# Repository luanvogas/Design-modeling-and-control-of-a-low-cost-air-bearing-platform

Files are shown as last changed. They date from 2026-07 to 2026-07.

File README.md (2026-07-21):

# Design, modeling, and control of a low-cost air-bearing platform

<div align="center">

This repository contains files produced as part of the doctoral thesis.

**Author:** Luan Mateus Bocalan Vogás  
**Advisor:** Prof. Dr. Roberto Kawakami Harrop Galvão  
**Co-Advisor:** Profa. Dra. Gabriela Werner Gabriel  

Instituto Tecnológico de Aeronáutica (ITA)  
Electronics Engineering Division  
São José dos Campos, SP, Brazil  
2026

</div>

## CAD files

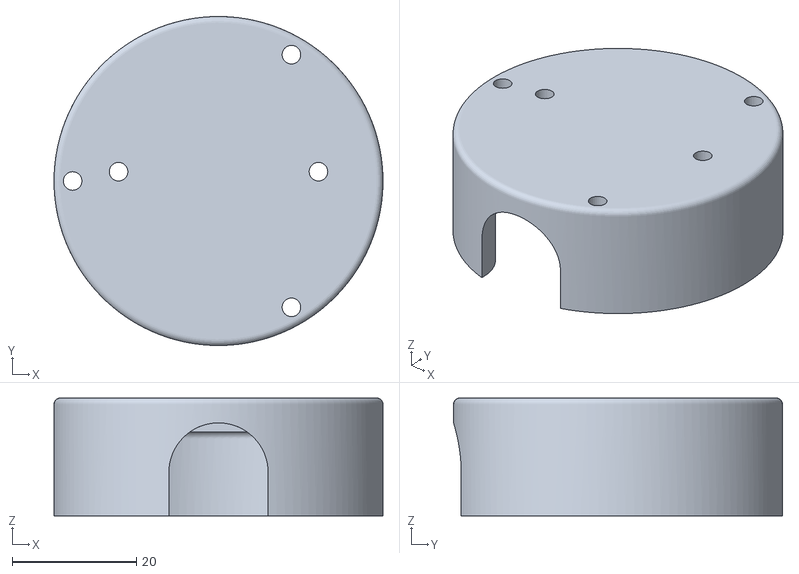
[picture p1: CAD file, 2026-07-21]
3D_models/A17_Main_part_bracket_IMU.stl
53.0 x 53.0 x 19.0

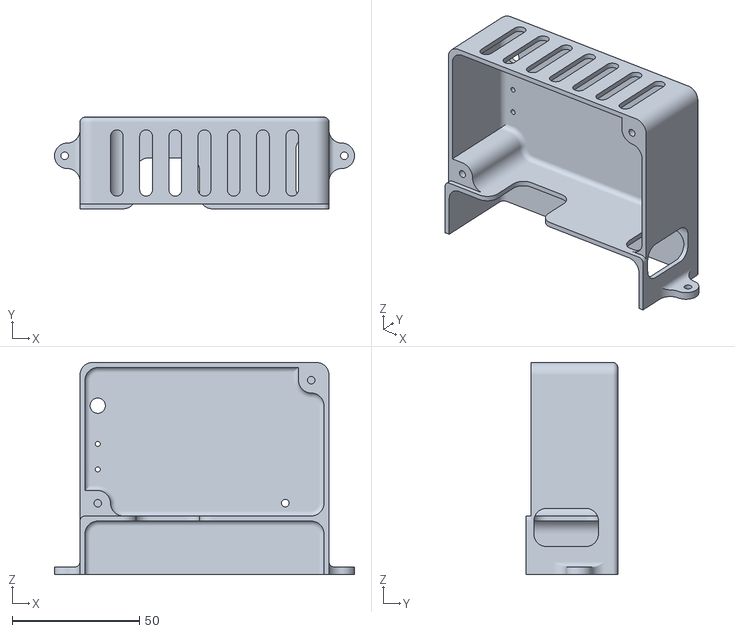
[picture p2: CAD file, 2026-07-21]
3D_models/A14_Main_part_box_electronic_boards.stl
117.8 x 36.0 x 83.3

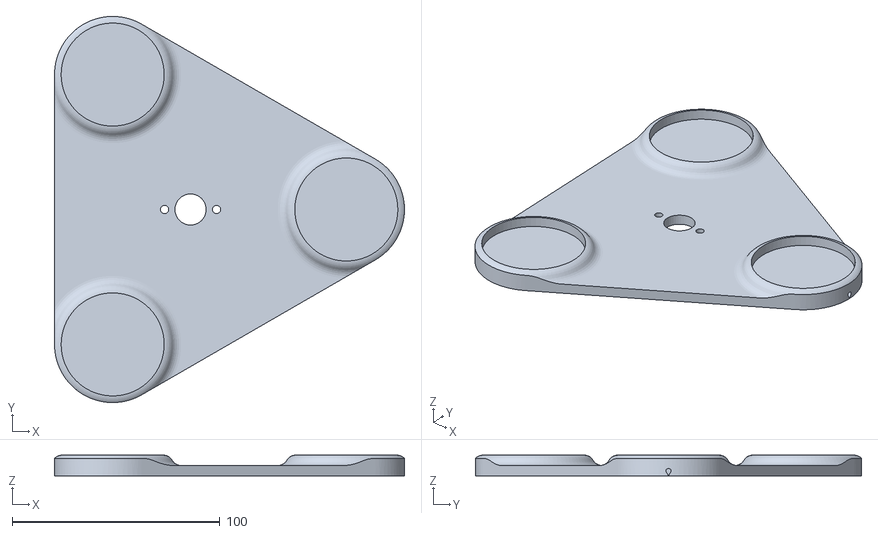
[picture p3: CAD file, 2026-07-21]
3D_models/A23_Support_servo_camera_calibration.stl
168.5 x 185.9 x 10.0

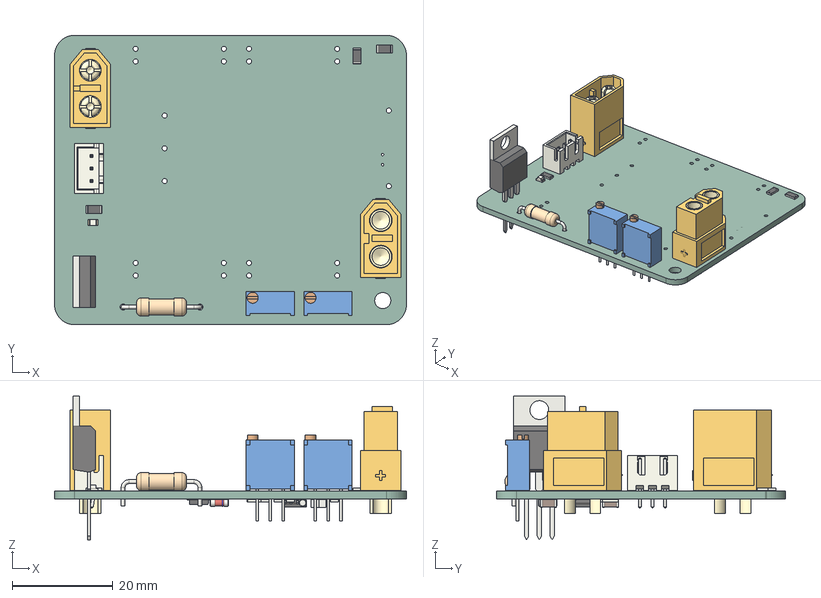
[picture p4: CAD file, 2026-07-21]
PCBs/Primary_Circuit_Board/Primary_Circuit_Board.step
69.9 x 57.4 x 28.5 mm
R_1206_3216Metric x 13
XT60 female v5
R_Axial_DIN0411_L99mm_D36mm_P1524mm_Horizontal
JST_B3B_XH_A
TO-220-3_Vertical
Potentiometer_Bourns_3296W_Vertical x 2
XT60 male v9
LED_0805_2012Metric
D_MiniMELF_Standard x 3
C_1206_3216Metric x 2
D_SOD-128
SOIC-8-1EP_3.9x4.9mm_P1.27mm_EP2.29x3mm
Power_Supply_Board_PCB

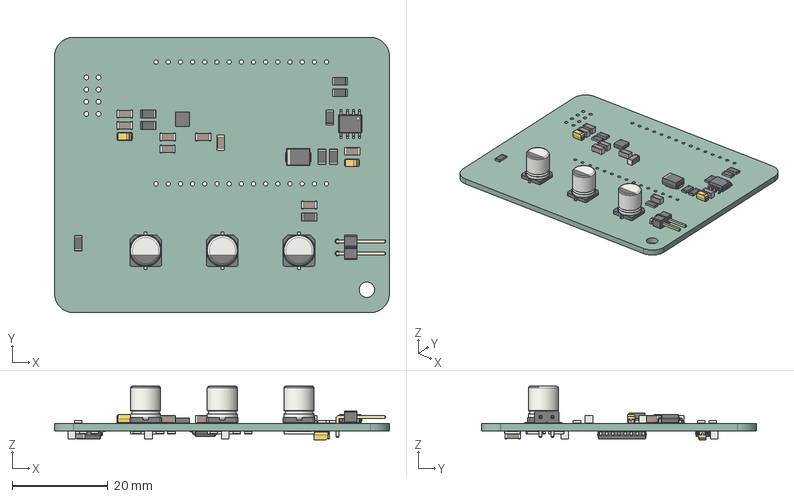
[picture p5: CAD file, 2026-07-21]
PCBs/Secondary_Circuit_Board/Secondary_Circuit_Board.step
69.9 x 57.4 x 11.2 mm
CP_Elec_63x77 x 3
R_1206_3216Metric x 20
SOIC_8_39x49mm_P127mm
C_1206_3216Metric x 13
CP_EIA_3216_18_Kemet_A x 3
D_SMB
LGA_16_3x3mm_P05mm
PinHeader_1x02_P254mm_Horizontal
SOIC_16W_75x128mm_P127mm
R_2512_6332Metric x 6
TSSOP_8_44x3mm_P065mm
Electronics_PCB

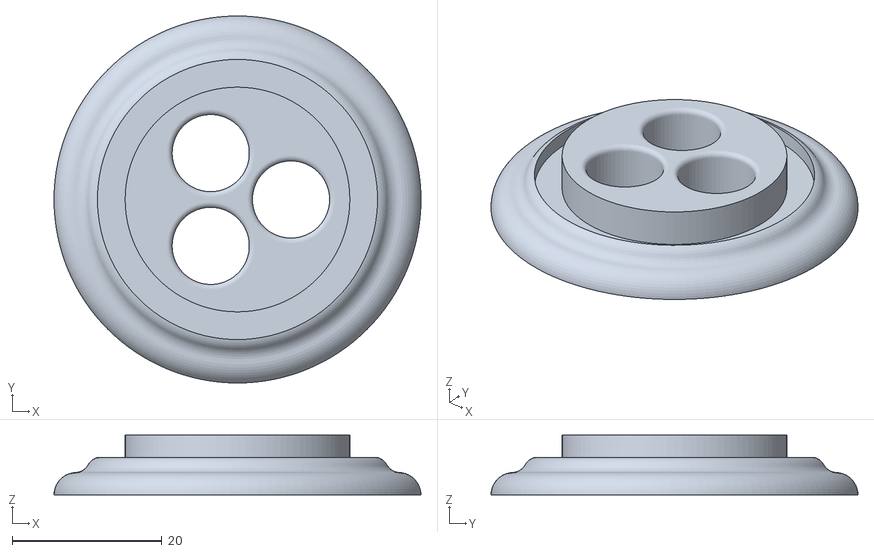
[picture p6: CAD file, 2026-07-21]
3D_models/A1_Air_bearing_base.stl
49.0 x 49.0 x 8.00

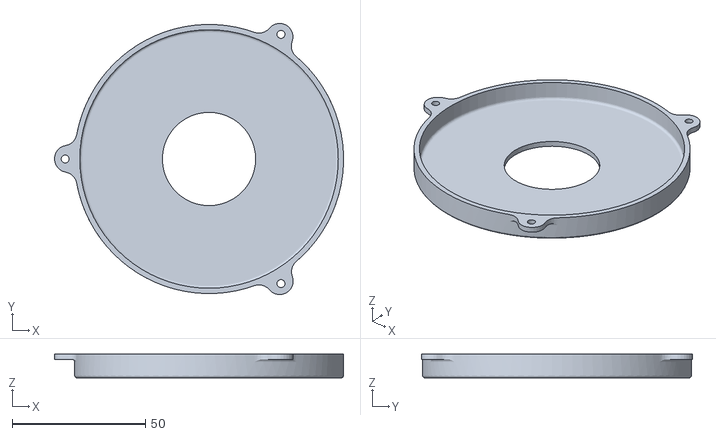
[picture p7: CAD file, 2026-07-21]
3D_models/A6_Cover_reaction_wheel.stl
108.5 x 101.8 x 9.00

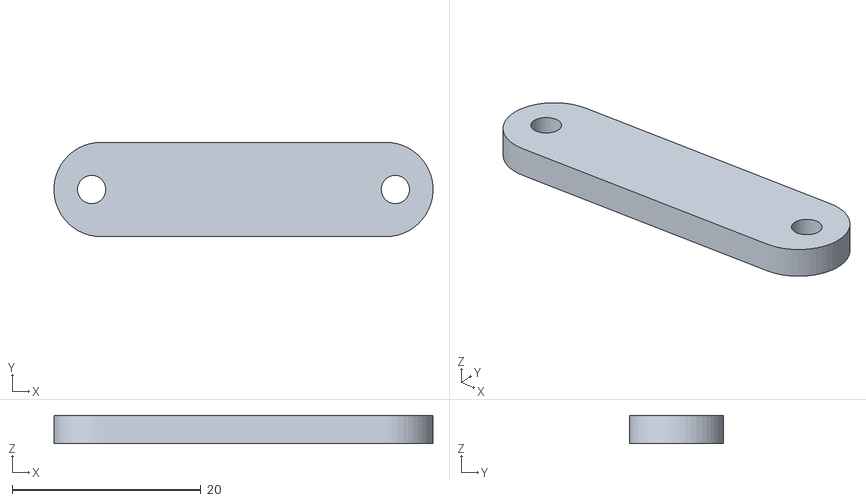
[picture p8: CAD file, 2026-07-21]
3D_models/A18_Bracket_hold_IMU_case.stl
40.2 x 10.0 x 3.00

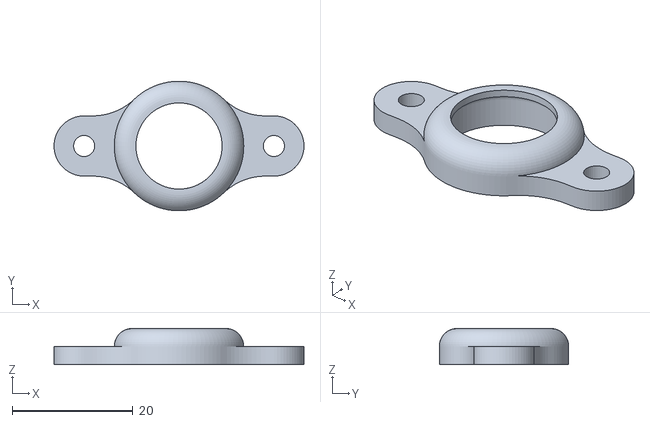
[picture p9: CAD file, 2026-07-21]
3D_models/A4_Spherical_bearing_support.stl
41.5 x 21.5 x 6.00

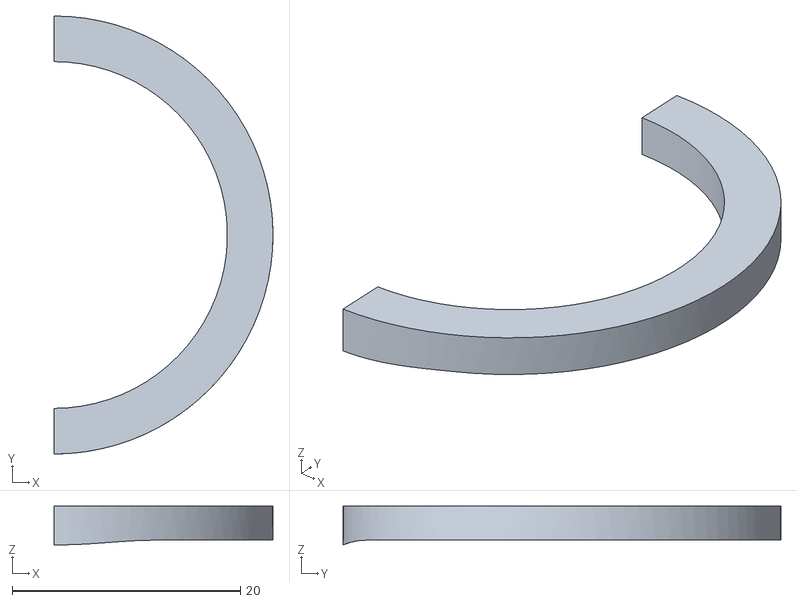
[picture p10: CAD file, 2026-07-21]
3D_models/A13_Part_2_support_pressure_regulator.stl
19.2 x 38.4 x 3.42

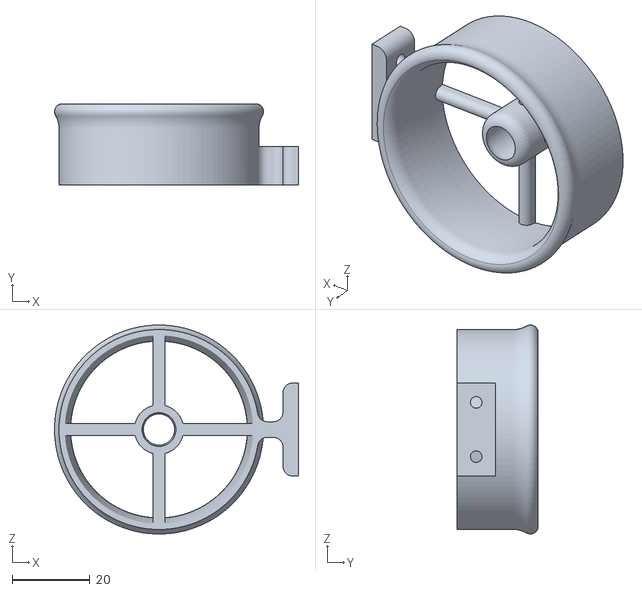
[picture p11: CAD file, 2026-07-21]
3D_models/A9_Disturbance_motor_bracket.stl
63.0 x 21.0 x 53.9

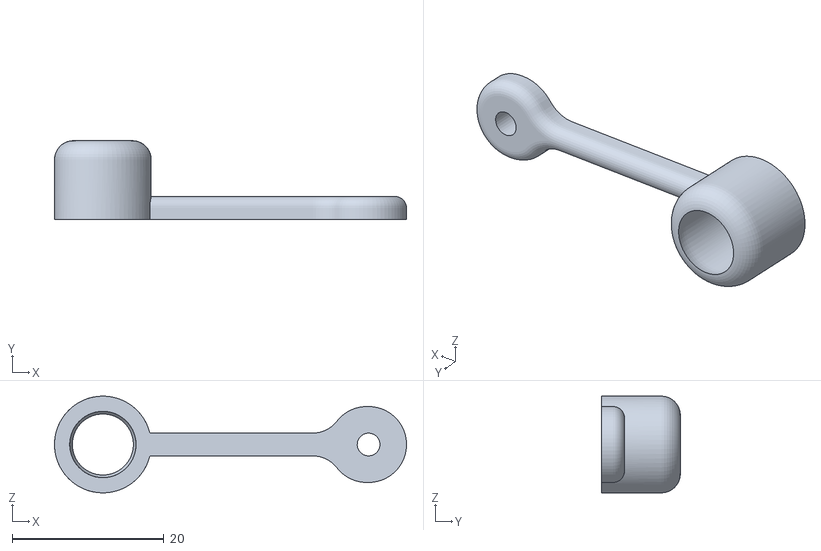
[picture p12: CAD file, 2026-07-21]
3D_models/A29_Support_motor_load_cell_without_duct.stl
46.4 x 10.4 x 12.7

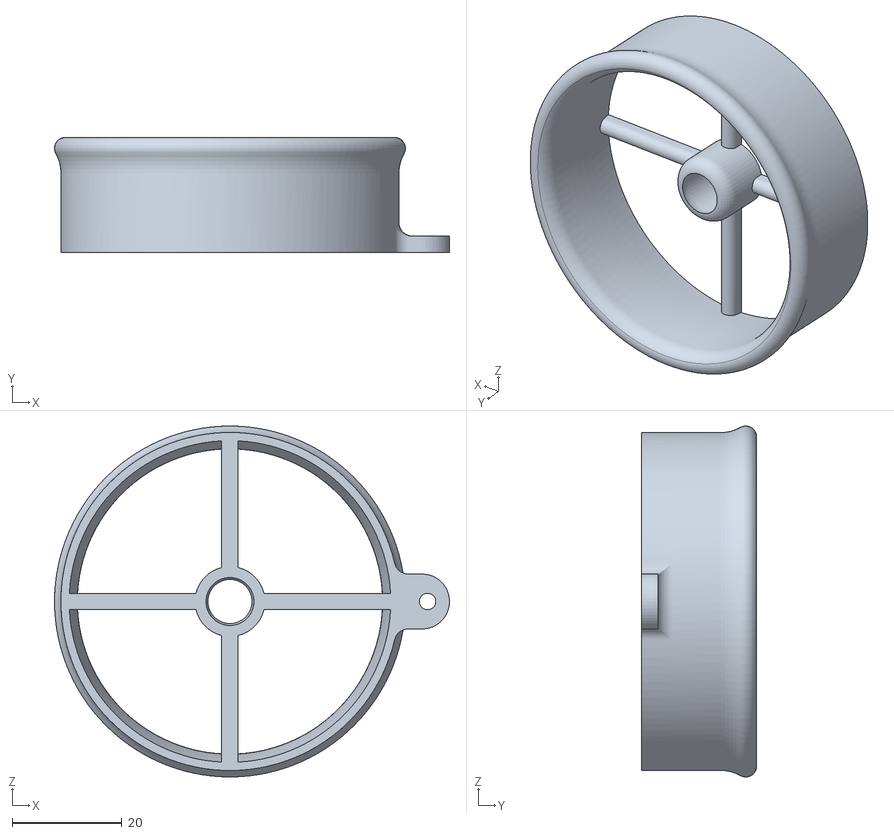
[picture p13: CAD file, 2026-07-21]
3D_models/A31_Support_motor_load_cell_55mm_duct.stl
72.0 x 21.0 x 63.9

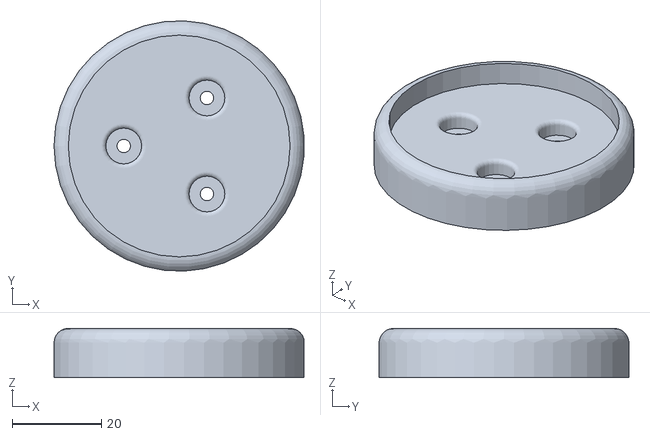
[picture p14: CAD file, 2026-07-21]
3D_models/A27_Bearing_support_RW_characterization_struture.stl
55.9 x 56.0 x 11.0

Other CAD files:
3D_models/A24_Support_table_camera_calibration.stl
3D_models/A19_Bracket_battery.stl
3D_models/A8_Top_floor_platform.stl
3D_models/A25_Lower_disc_RW_characterization_struture.stl
3D_models/A10_Part_1_support_PET_bottle.stl
3D_models/A11_Part_2_support_PET_bottle.stl
3D_models/A12_Part_1_support_pressure_regulator.stl
3D_models/A15_Bottom_part_box_electronic_boards.stl
3D_models/A16_Top_cover_box_electronic_boards.stl
3D_models/A20_Support_ArUco_marker.stl
3D_models/A21_Part_1_auxiliary_support_ArUco.stl
3D_models/A22_Part_2_auxiliary_support_ArUco.stl
3D_models/A26_Upper_disc_RW_characterization_struture.stl
3D_models/A28_Support_line_RW_characterization_struture.stl
3D_models/A2_Air_bearing_cover.stl
3D_models/A30_Support_motor_load_cell_45mm_duct.stl
3D_models/A3_Air_bearing_fixing_bracket.stl
3D_models/A5_Bottom_floor_platform.stl
3D_models/A7_Bottom_floor_motor_bracket.stl

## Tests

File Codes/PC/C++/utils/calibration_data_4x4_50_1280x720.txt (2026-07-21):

%YAML:1.0
---
calibration_time: "Mon Dec  4 14:02:41 2023"
image_width: 1280
image_height: 720
flags: 0
camera_matrix: !!opencv-matrix
   rows: 3
   cols: 3
   dt: d
   data: [ 9.6003079017747950e+02, 0., 6.4759114083780116e+02, 0.,
       9.6057532993660845e+02, 3.5647079880607180e+02, 0., 0., 1. ]
distortion_coefficients: !!opencv-matrix
   rows: 1
   cols: 5
   dt: d
   data: [ 8.0410259950618707e-02, -3.2936306621087619e-01,
       2.5844360184622602e-03, 1.5253495226606067e-05,
       3.5463308602818394e-01 ]
avg_reprojection_error: 9.7660139921601419e-01

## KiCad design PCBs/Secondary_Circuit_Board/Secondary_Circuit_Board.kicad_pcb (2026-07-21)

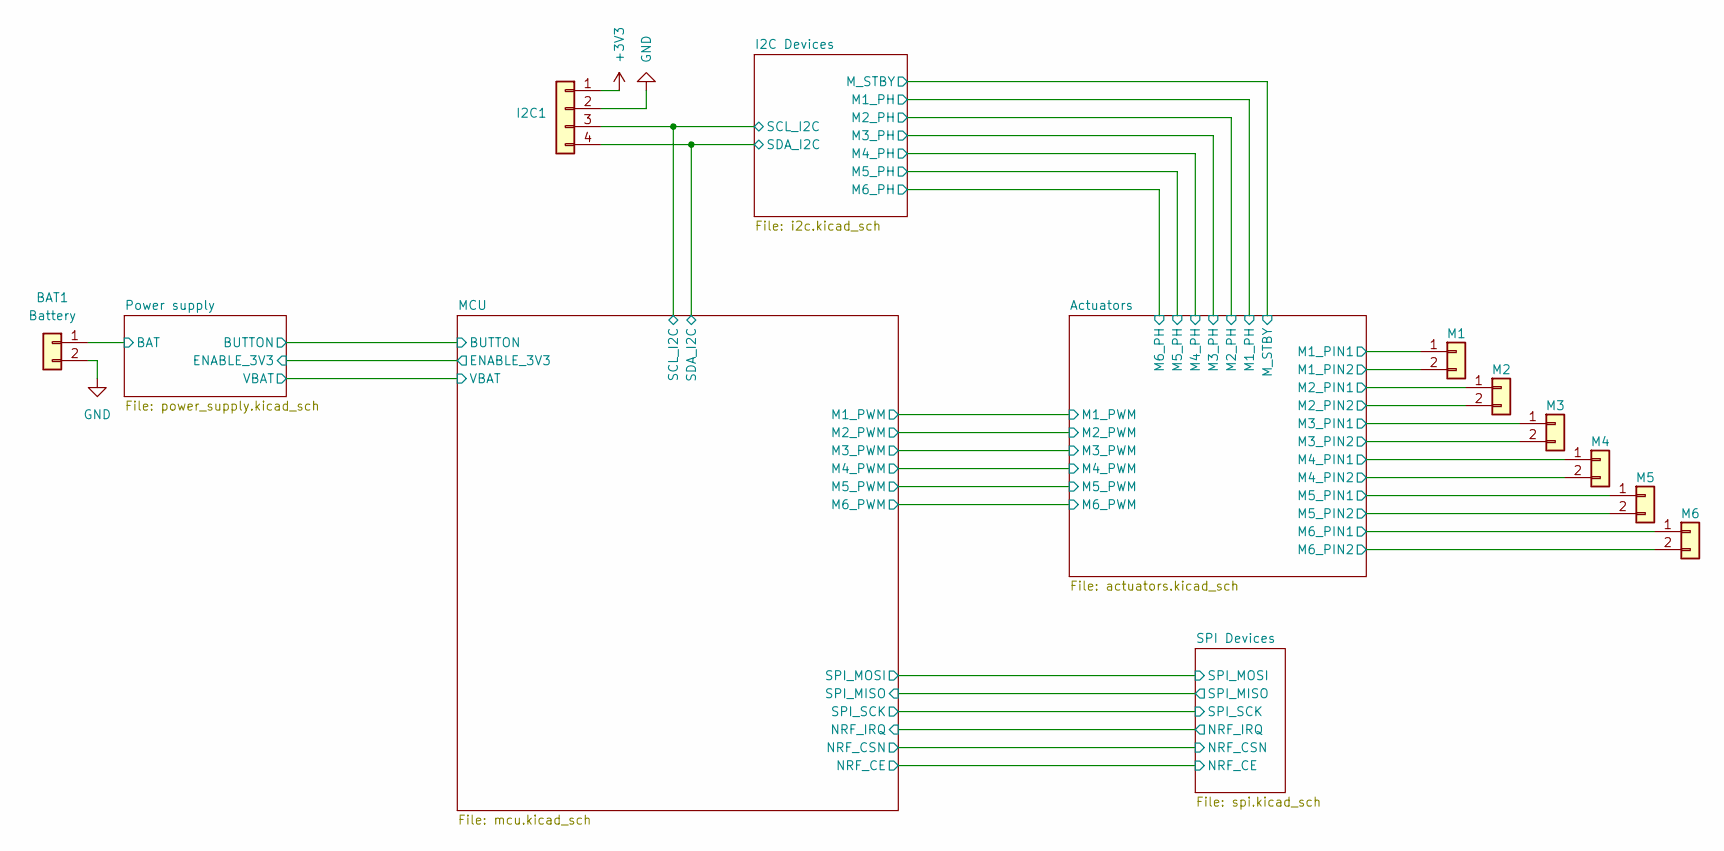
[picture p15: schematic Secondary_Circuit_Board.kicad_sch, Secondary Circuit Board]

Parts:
BAT1: Battery; PinHeader_1x02_P2.54mm_Horizontal
I2C1: I2C; JST_SH_BM04B-SRSS-TB_1x04-1MP_P1.00mm_Vertical
M1: M1; JST_SH_BM02B-SRSS-TB_1x02-1MP_P1.00mm_Vertical
M2: M2; JST_SH_BM02B-SRSS-TB_1x02-1MP_P1.00mm_Vertical
M3: M3; JST_SH_BM02B-SRSS-TB_1x02-1MP_P1.00mm_Vertical
M4: M4; JST_SH_BM02B-SRSS-TB_1x02-1MP_P1.00mm_Vertical
M5: M5; JST_SH_BM02B-SRSS-TB_1x02-1MP_P1.00mm_Vertical
M6: M6; JST_SH_BM02B-SRSS-TB_1x02-1MP_P1.00mm_Vertical

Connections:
+3V3: I2C1.1; also elsewhere on the board
/Actuators/M1_PIN1: M1.1; also elsewhere on the board
/Actuators/M1_PIN2: M1.2; also elsewhere on the board
/Actuators/M2_PIN1: M2.1; also elsewhere on the board
/Actuators/M2_PIN2: M2.2; also elsewhere on the board
/Actuators/M3_PIN1: M3.1; also elsewhere on the board
/Actuators/M3_PIN2: M3.2; also elsewhere on the board
/Actuators/M4_PIN1: M4.1; also elsewhere on the board
/Actuators/M4_PIN2: M4.2; also elsewhere on the board
/Actuators/M5_PIN1: M5.1; also elsewhere on the board
/Actuators/M5_PIN2: M5.2; also elsewhere on the board
/Actuators/M6_PIN1: M6.1; also elsewhere on the board
/Actuators/M6_PIN2: M6.2; also elsewhere on the board
/I2C Devices/SCL_I2C: I2C1.3; also elsewhere on the board
/I2C Devices/SDA_I2C: I2C1.4; also elsewhere on the board
GND: BAT1.2, I2C1.2; also elsewhere on the board
VCC: BAT1.1; also elsewhere on the board

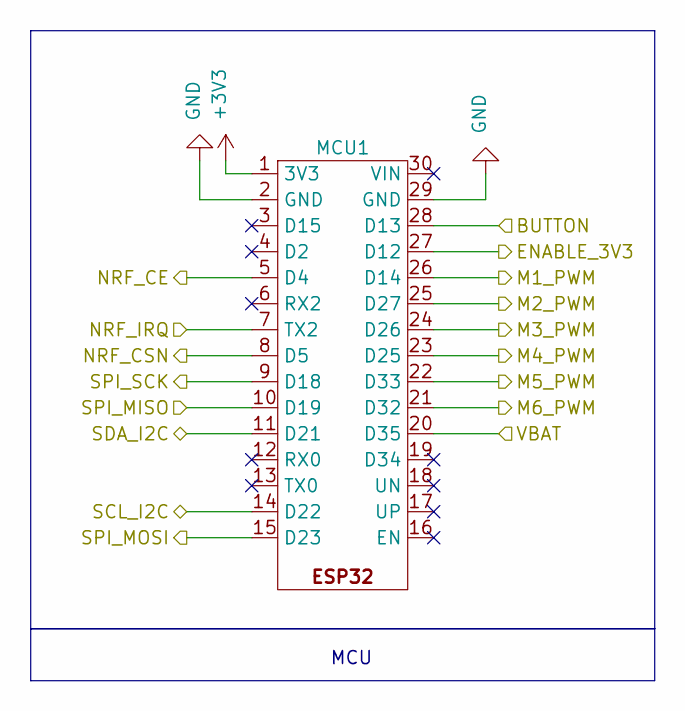
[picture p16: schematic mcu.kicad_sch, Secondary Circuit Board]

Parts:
MCU1: ESP32

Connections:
+3V3: MCU1.1 (3V3); also elsewhere on the board
/Actuators/M1_PWM: MCU1.26 (D14); also elsewhere on the board
/Actuators/M2_PWM: MCU1.25 (D27); also elsewhere on the board
/Actuators/M3_PWM: MCU1.24 (D26); also elsewhere on the board
/Actuators/M4_PWM: MCU1.23 (D25); also elsewhere on the board
/Actuators/M5_PWM: MCU1.22 (D33); also elsewhere on the board
/Actuators/M6_PWM: MCU1.21 (D32); also elsewhere on the board
/I2C Devices/SCL_I2C: MCU1.14 (D22); also elsewhere on the board
/I2C Devices/SDA_I2C: MCU1.11 (D21); also elsewhere on the board
/MCU/BUTTON: MCU1.28 (D13); also elsewhere on the board
/MCU/ENABLE_3V3: MCU1.27 (D12); also elsewhere on the board
/MCU/NRF_CE: MCU1.5 (D4); also elsewhere on the board
/MCU/NRF_CSN: MCU1.8 (D5); also elsewhere on the board
/MCU/NRF_IRQ: MCU1.7 (TX2); also elsewhere on the board
/MCU/SPI_MISO: MCU1.10 (D19); also elsewhere on the board
/MCU/SPI_MOSI: MCU1.15 (D23); also elsewhere on the board
/MCU/SPI_SCK: MCU1.9 (D18); also elsewhere on the board
/MCU/VBAT: MCU1.20 (D35); also elsewhere on the board
GND: MCU1.2 (GND), MCU1.29 (GND); also elsewhere on the board

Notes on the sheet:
MCU

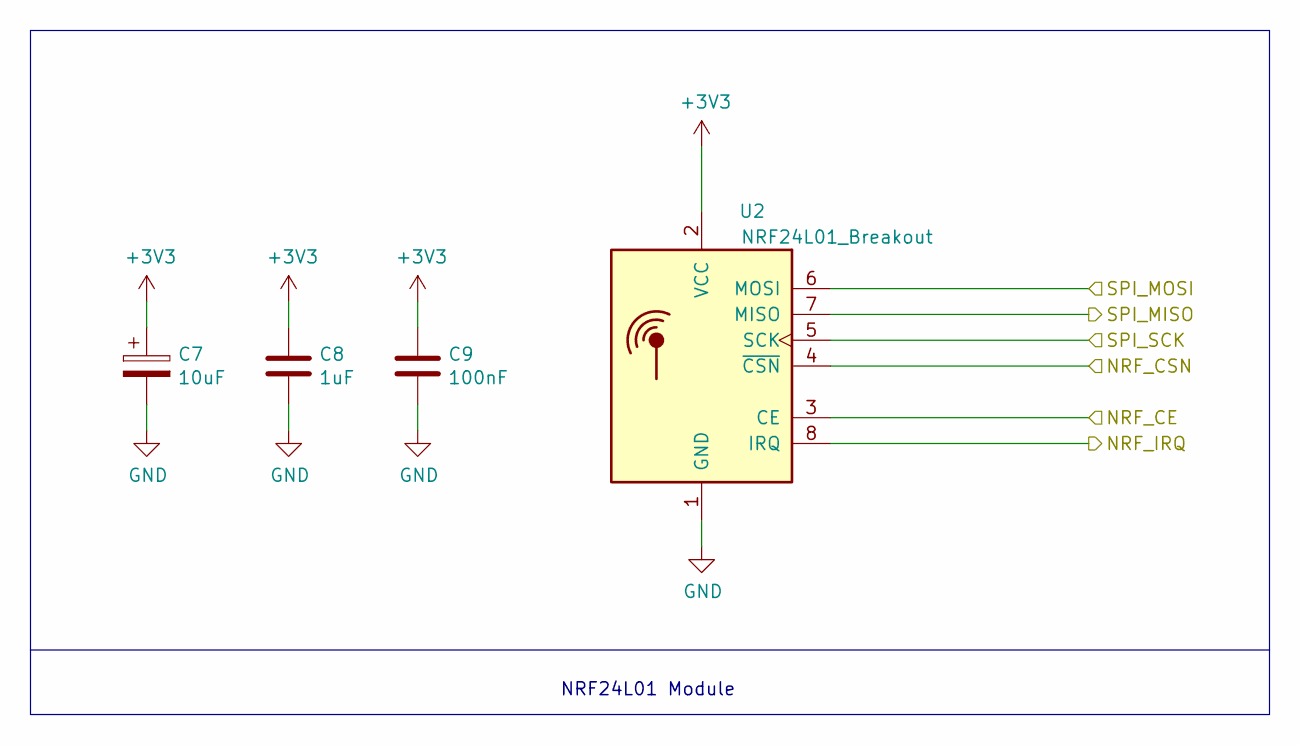
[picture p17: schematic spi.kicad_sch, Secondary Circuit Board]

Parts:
C7: 10uF; CP_EIA-3216-18_Kemet-A
C8: 1uF; C_1206_3216Metric
C9: 100nF; C_1206_3216Metric
U2: NRF24L01_Breakout; nRF24L01_Breakout

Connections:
+3V3: C7.1, C8.1, C9.1, U2.2 (VCC); also elsewhere on the board
/MCU/NRF_CE: U2.3 (CE); also elsewhere on the board
/MCU/NRF_CSN: U2.4 (~CSN); also elsewhere on the board
/MCU/NRF_IRQ: U2.8 (IRQ); also elsewhere on the board
/MCU/SPI_MISO: U2.7 (MISO); also elsewhere on the board
/MCU/SPI_MOSI: U2.6 (MOSI); also elsewhere on the board
/MCU/SPI_SCK: U2.5 (SCK); also elsewhere on the board
GND: C7.2, C8.2, C9.2, U2.1 (GND); also elsewhere on the board

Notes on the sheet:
NRF24L01 Module

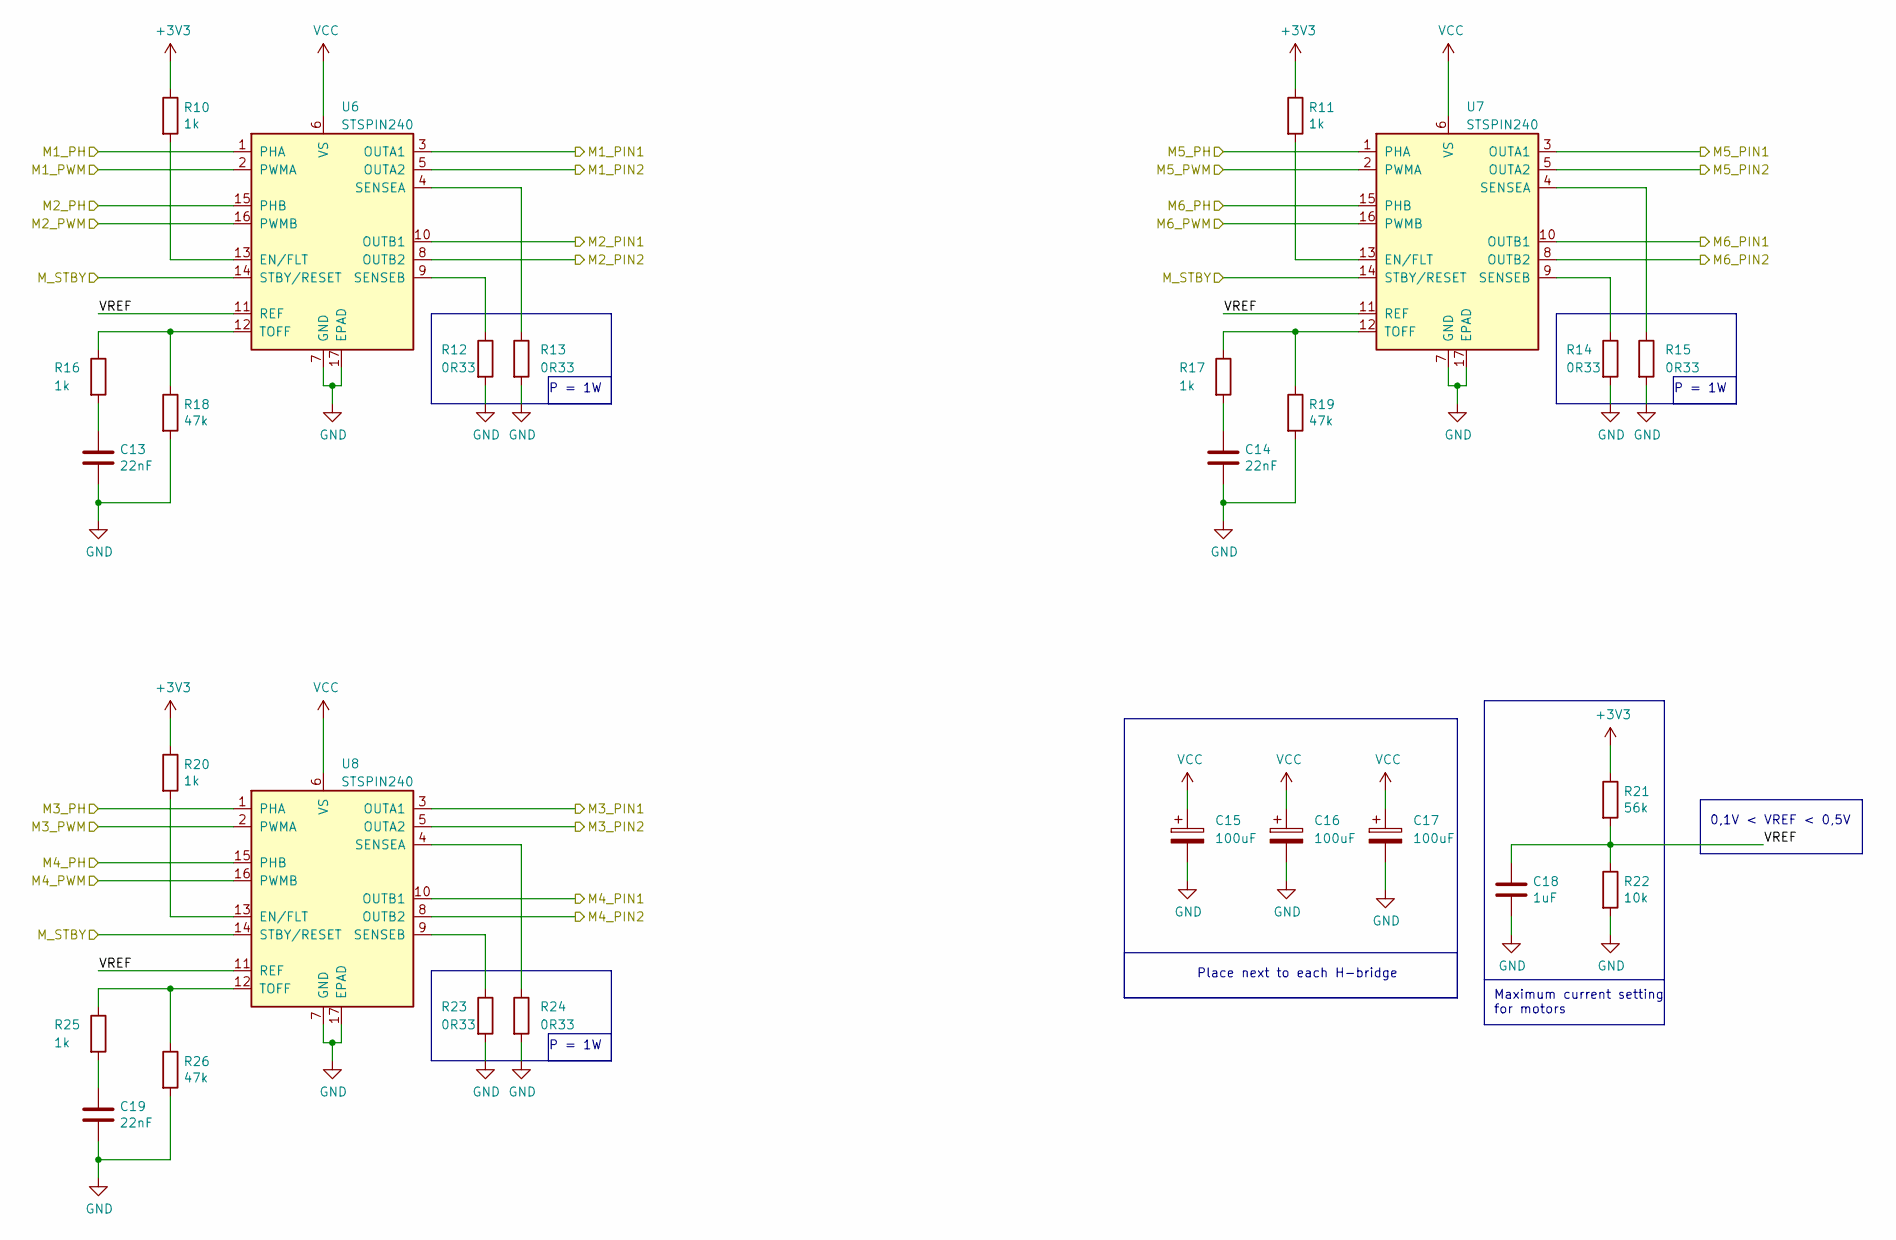
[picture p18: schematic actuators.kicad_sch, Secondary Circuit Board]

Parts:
C13, C14, C19: 22nF; C_1206_3216Metric
C15, C16, C17: 100uF; CP_Elec_6.3x7.7
C18: 1uF; C_1206_3216Metric
R10, R11, R16, R17, R20, R25: 1k; R_1206_3216Metric
R12, R13, R14, R15, R23, R24: 0R33; R_2512_6332Metric
R18, R19, R26: 47k; R_1206_3216Metric
R21: 56k; R_1206_3216Metric
R22: 10k; R_1206_3216Metric
U6, U7, U8: STSPIN240; PADS_COMPRIDOS_VQFN-16-1EP_3x3mm_P0.5mm_EP1.8x1.8mm

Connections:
+3V3: R10.1, R11.1, R20.1, R21.1; also elsewhere on the board
/Actuators/M1_PH: U6.1 (PHA); also elsewhere on the board
/Actuators/M1_PIN1: U6.3 (OUTA1); also elsewhere on the board
/Actuators/M1_PIN2: U6.5 (OUTA2); also elsewhere on the board
/Actuators/M1_PWM: U6.2 (PWMA); also elsewhere on the board
/Actuators/M2_PH: U6.15 (PHB); also elsewhere on the board
/Actuators/M2_PIN1: U6.10 (OUTB1); also elsewhere on the board
/Actuators/M2_PIN2: U6.8 (OUTB2); also elsewhere on the board
/Actuators/M2_PWM: U6.16 (PWMB); also elsewhere on the board
/Actuators/M3_PH: U8.1 (PHA); also elsewhere on the board
/Actuators/M3_PIN1: U8.3 (OUTA1); also elsewhere on the board
/Actuators/M3_PIN2: U8.5 (OUTA2); also elsewhere on the board
/Actuators/M3_PWM: U8.2 (PWMA); also elsewhere on the board
/Actuators/M4_PH: U8.15 (PHB); also elsewhere on the board
/Actuators/M4_PIN1: U8.10 (OUTB1); also elsewhere on the board
/Actuators/M4_PIN2: U8.8 (OUTB2); also elsewhere on the board
/Actuators/M4_PWM: U8.16 (PWMB); also elsewhere on the board
/Actuators/M5_PH: U7.1 (PHA); also elsewhere on the board
/Actuators/M5_PIN1: U7.3 (OUTA1); also elsewhere on the board
/Actuators/M5_PIN2: U7.5 (OUTA2); also elsewhere on the board
/Actuators/M5_PWM: U7.2 (PWMA); also elsewhere on the board
/Actuators/M6_PH: U7.15 (PHB); also elsewhere on the board
/Actuators/M6_PIN1: U7.10 (OUTB1); also elsewhere on the board
/Actuators/M6_PIN2: U7.8 (OUTB2); also elsewhere on the board
/Actuators/M6_PWM: U7.16 (PWMB); also elsewhere on the board
/Actuators/M_STBY: U6.14 (STBY/RESET), U7.14 (STBY/RESET), U8.14 (STBY/RESET); also elsewhere on the board
/Actuators/VREF: C18.1, R21.2, R22.1, U6.11 (REF), U7.11 (REF), U8.11 (REF)
GND: C13.2, C14.2, C15.2, C16.2, C17.2, C18.2, C19.2, R12.2, R13.2, R14.2, R15.2, R18.2, R19.2, R22.2, R23.2, R24.2, R26.2, U6.7 (GND), U6.17 (EPAD), U7.7 (GND), U7.17 (EPAD), U8.7 (GND), U8.17 (EPAD); also elsewhere on the board
unnamed: C13.1, R16.2
unnamed: C14.1, R17.2
unnamed: C19.1, R25.2
unnamed: R10.2, U6.13 (EN/FLT)
unnamed: R13.1, U6.4 (SENSEA)
unnamed: R12.1, U6.9 (SENSEB)
unnamed: R16.1, R18.1, U6.12 (TOFF)
unnamed: R11.2, U7.13 (EN/FLT)
unnamed: R15.1, U7.4 (SENSEA)
unnamed: R14.1, U7.9 (SENSEB)
unnamed: R17.1, R19.1, U7.12 (TOFF)
unnamed: R20.2, U8.13 (EN/FLT)
unnamed: R24.1, U8.4 (SENSEA)
unnamed: R23.1, U8.9 (SENSEB)
unnamed: R25.1, R26.1, U8.12 (TOFF)
VCC: C15.1, C16.1, C17.1, U6.6 (VS), U7.6 (VS), U8.6 (VS); also elsewhere on the board

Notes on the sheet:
0,1V < VREF < 0,5V
Maximum current setting for motors
P = 1W
Place next to each H-bridge

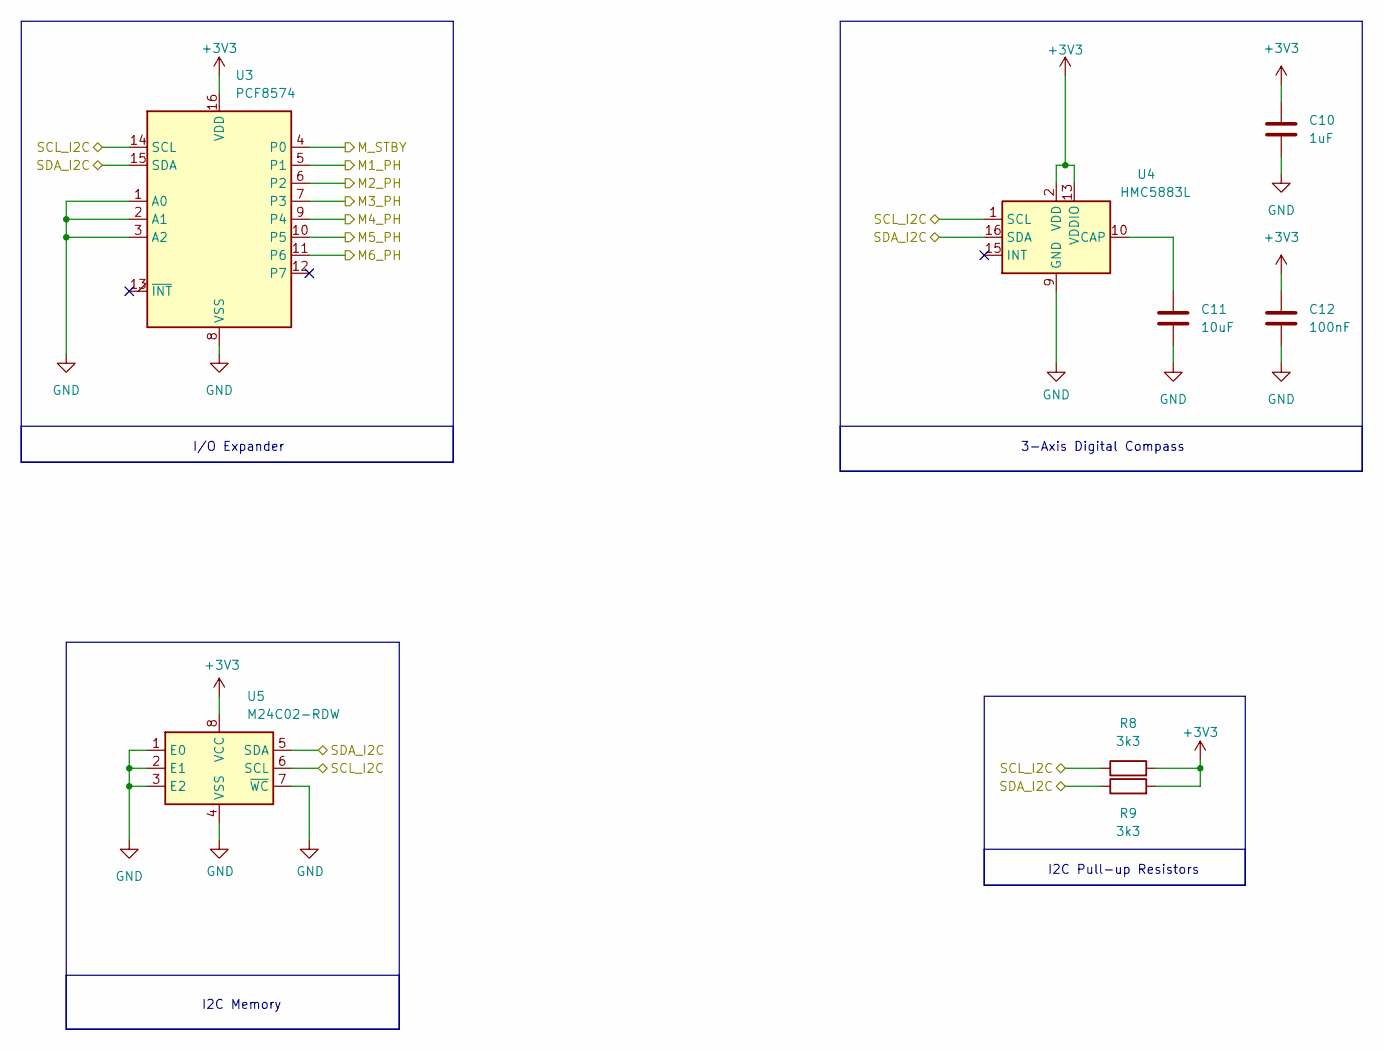
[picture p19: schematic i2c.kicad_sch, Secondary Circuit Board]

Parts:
C10: 1uF; C_1206_3216Metric
C11: 10uF; C_1206_3216Metric
C12: 100nF; C_1206_3216Metric
R8, R9: 3k3; R_1206_3216Metric
U3: PCF8574; SOIC-16W_7.5x12.8mm_P1.27mm
U4: HMC5883L; LGA-16_3x3mm_P0.5mm
U5: M24C02-RDW; TSSOP-8_4.4x3mm_P0.65mm

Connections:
+3V3: C10.1, C12.1, R8.2, R9.2, U3.16 (VDD), U4.2 (VDD), U4.13 (VDDIO), U5.8 (VCC); also elsewhere on the board
/Actuators/M1_PH: U3.5 (P1); also elsewhere on the board
/Actuators/M2_PH: U3.6 (P2); also elsewhere on the board
/Actuators/M3_PH: U3.7 (P3); also elsewhere on the board
/Actuators/M4_PH: U3.9 (P4); also elsewhere on the board
/Actuators/M5_PH: U3.10 (P5); also elsewhere on the board
/Actuators/M6_PH: U3.11 (P6); also elsewhere on the board
/Actuators/M_STBY: U3.4 (P0); also elsewhere on the board
/I2C Devices/SCL_I2C: R8.1, U3.14 (SCL), U4.1 (SCL), U5.6 (SCL); also elsewhere on the board
/I2C Devices/SDA_I2C: R9.1, U3.15 (SDA), U4.16 (SDA), U5.5 (SDA); also elsewhere on the board
GND: C10.2, C11.2, C12.2, U3.1 (A0), U3.2 (A1), U3.3 (A2), U3.8 (VSS), U4.9 (GND), U4.11 (GND), U5.1 (E0), U5.2 (E1), U5.3 (E2), U5.4 (VSS), U5.7 (~WC); also elsewhere on the board
unnamed: C11.1, U4.10 (CAP)

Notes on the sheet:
I2C Pull-up Resistors
I2C Memory
3-Axis Digital Compass
I/O Expander

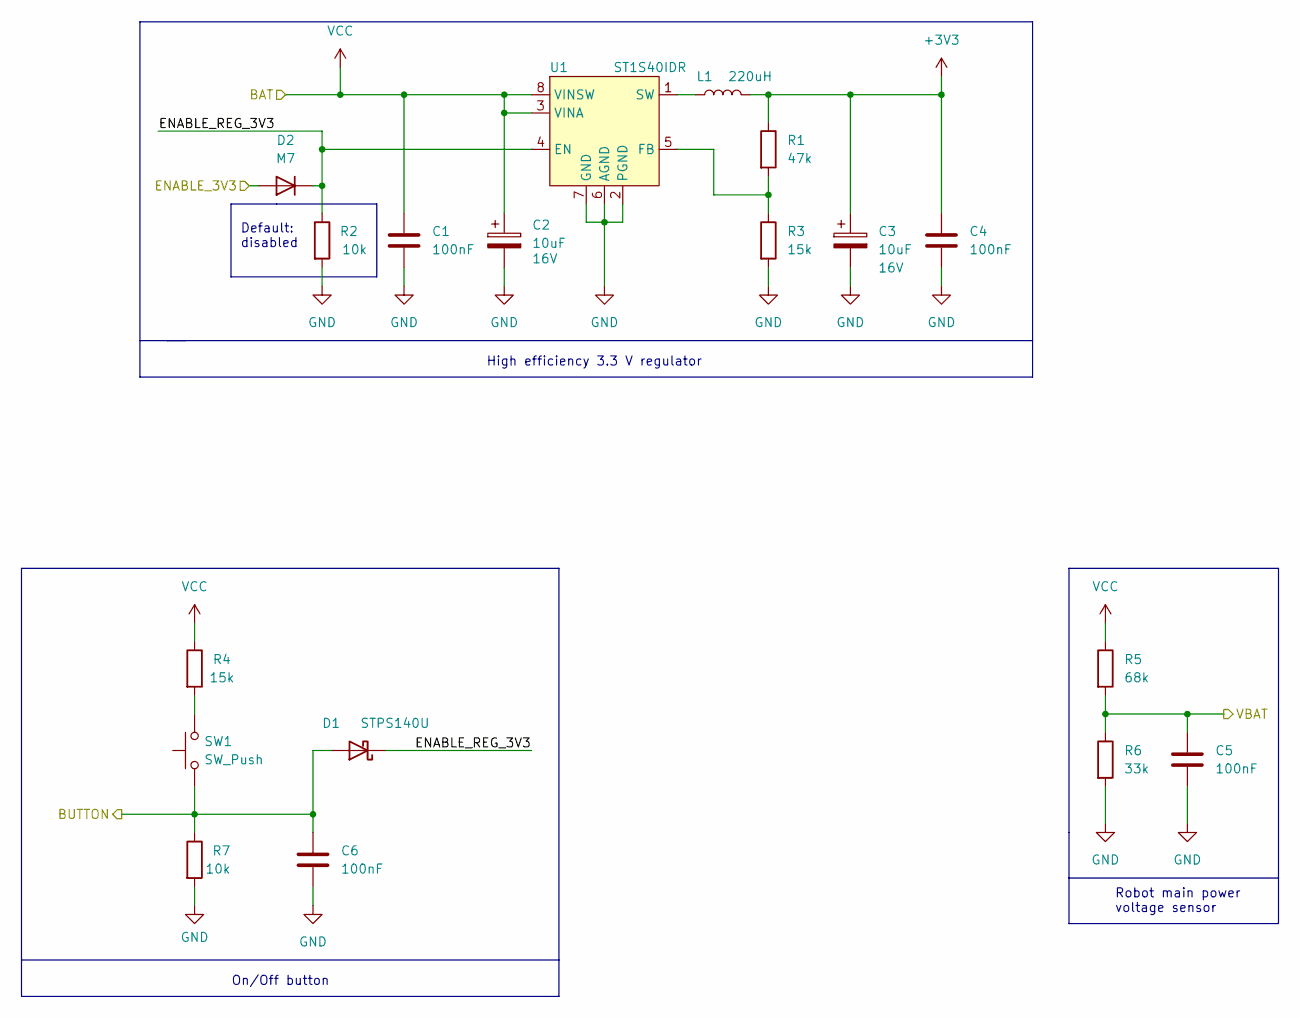
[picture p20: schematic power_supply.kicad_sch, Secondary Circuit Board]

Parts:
C1, C4, C5, C6: 100nF; C_1206_3216Metric
C2, C3: 10uF; CP_EIA-3216-18_Kemet-A_Pad1.58x1.35mm_HandSolder; Voltage 16V
D1: STPS140U; D_SMB
D2: M7; D_SMA
L1: 220uH; L_7.3x7.3_H4.5
R1: 47k; R_1206_3216Metric
R2, R7: 10k; R_1206_3216Metric
R3, R4: 15k; R_1206_3216Metric
R5: 68k; R_1206_3216Metric
R6: 33k; R_1206_3216Metric
SW1: SW_Push; SW_Push_1P1T_NO_CK_KMR2
U1: ST1S40IDR; SOIC-8_3.9x4.9mm_P1.27mm

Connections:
+3V3: C3.1, C4.1, L1.2, R1.1; also elsewhere on the board
/MCU/BUTTON: C6.1, D1.2 (A), R7.1, SW1.1; also elsewhere on the board
/MCU/ENABLE_3V3: D2.2 (A); also elsewhere on the board
/MCU/VBAT: C5.1, R5.2, R6.1; also elsewhere on the board
/Power supply/ENABLE_REG_3V3: D1.1 (K), D2.1 (K), R2.1, U1.4 (EN)
GND: C1.2, C2.2, C3.2, C4.2, C5.2, C6.2, R2.2, R3.2, R6.2, R7.2, U1.2 (PGND), U1.6 (AGND), U1.7 (GND); also elsewhere on the board
unnamed: R4.2, SW1.2
unnamed: R1.2, R3.1, U1.5 (FB)
unnamed: L1.1, U1.1 (SW)
VCC: C1.1, C2.1, R4.1, R5.1, U1.3 (VINA), U1.8 (VINSW); also elsewhere on the board

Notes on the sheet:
Default: disabled
High efficiency 3.3 V regulator
Robot main power voltage sensor
On/Off button

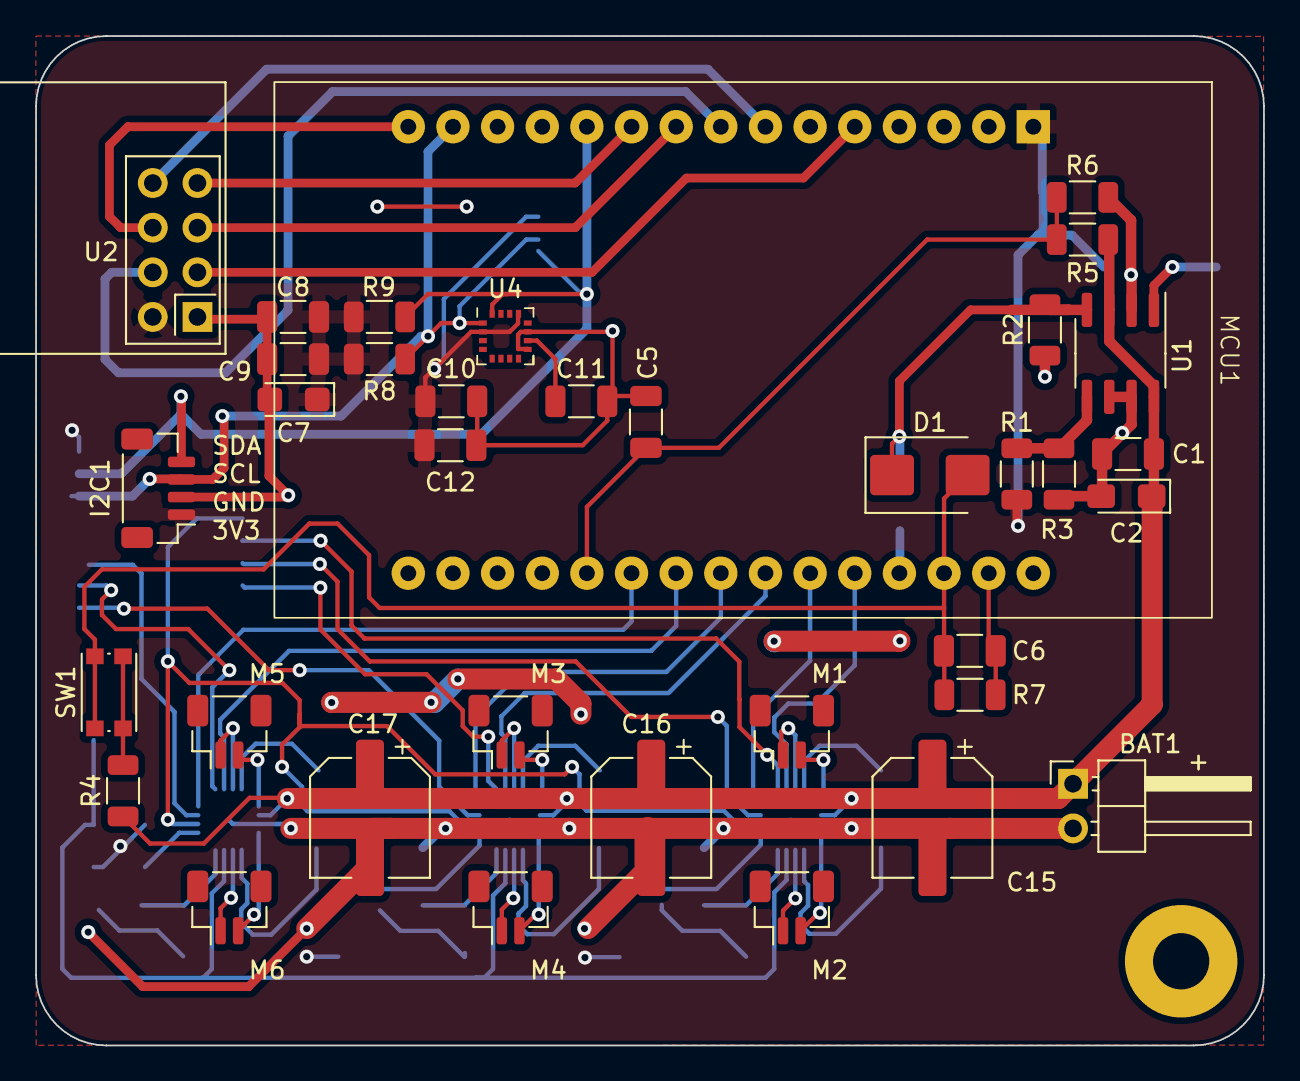
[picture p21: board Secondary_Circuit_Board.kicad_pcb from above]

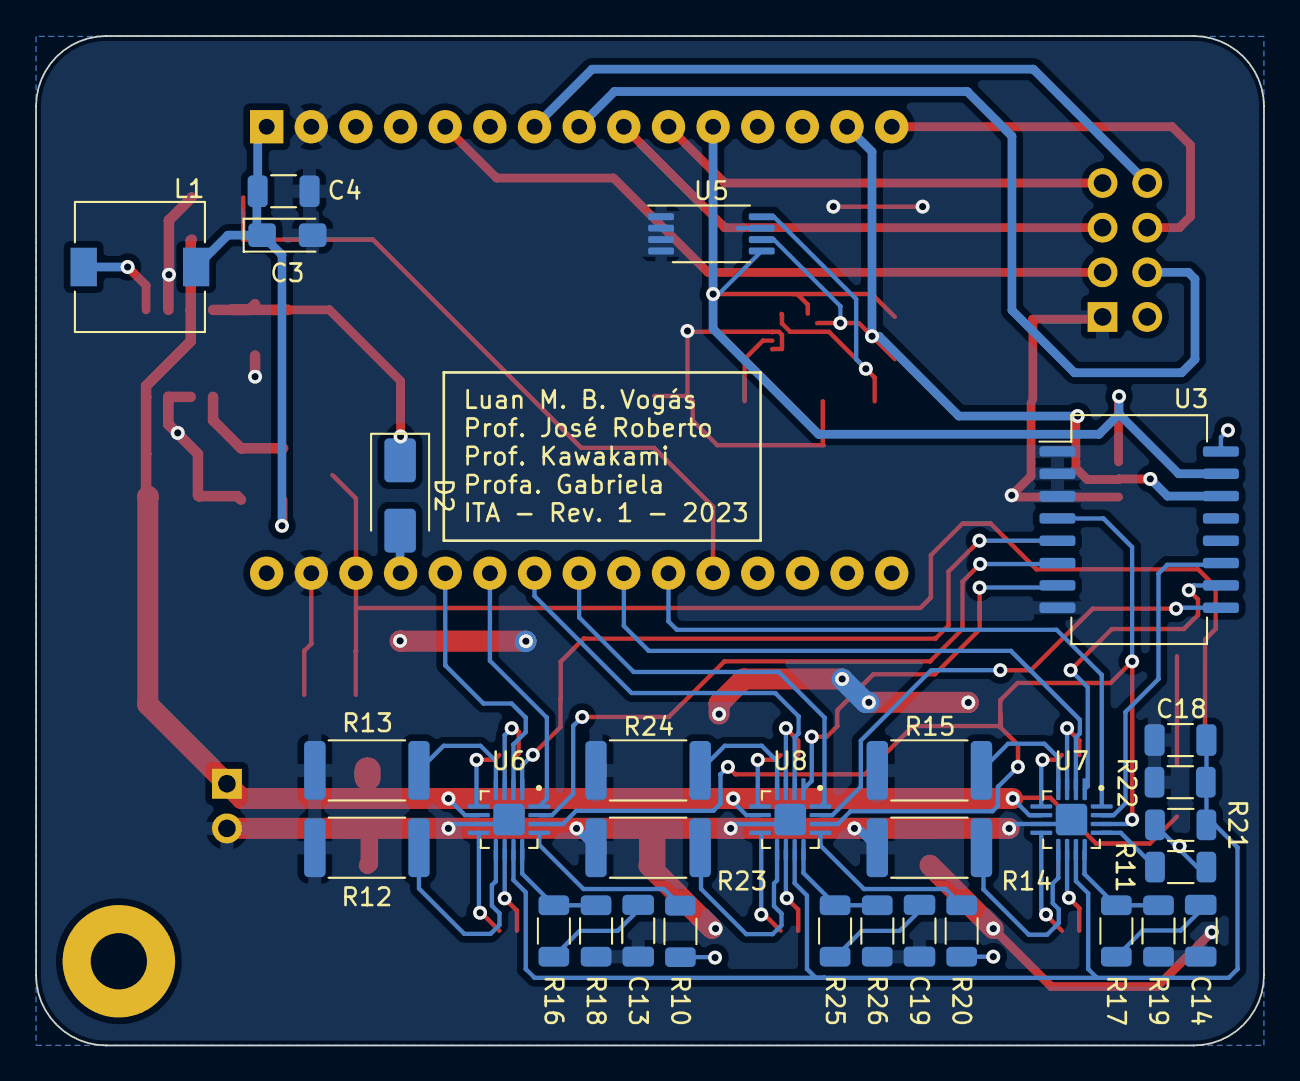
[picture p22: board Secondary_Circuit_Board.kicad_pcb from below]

Board: 2 copper layers, 69.9 x 57.4 mm, 66 parts (30 on the bottom side), 60 nets.

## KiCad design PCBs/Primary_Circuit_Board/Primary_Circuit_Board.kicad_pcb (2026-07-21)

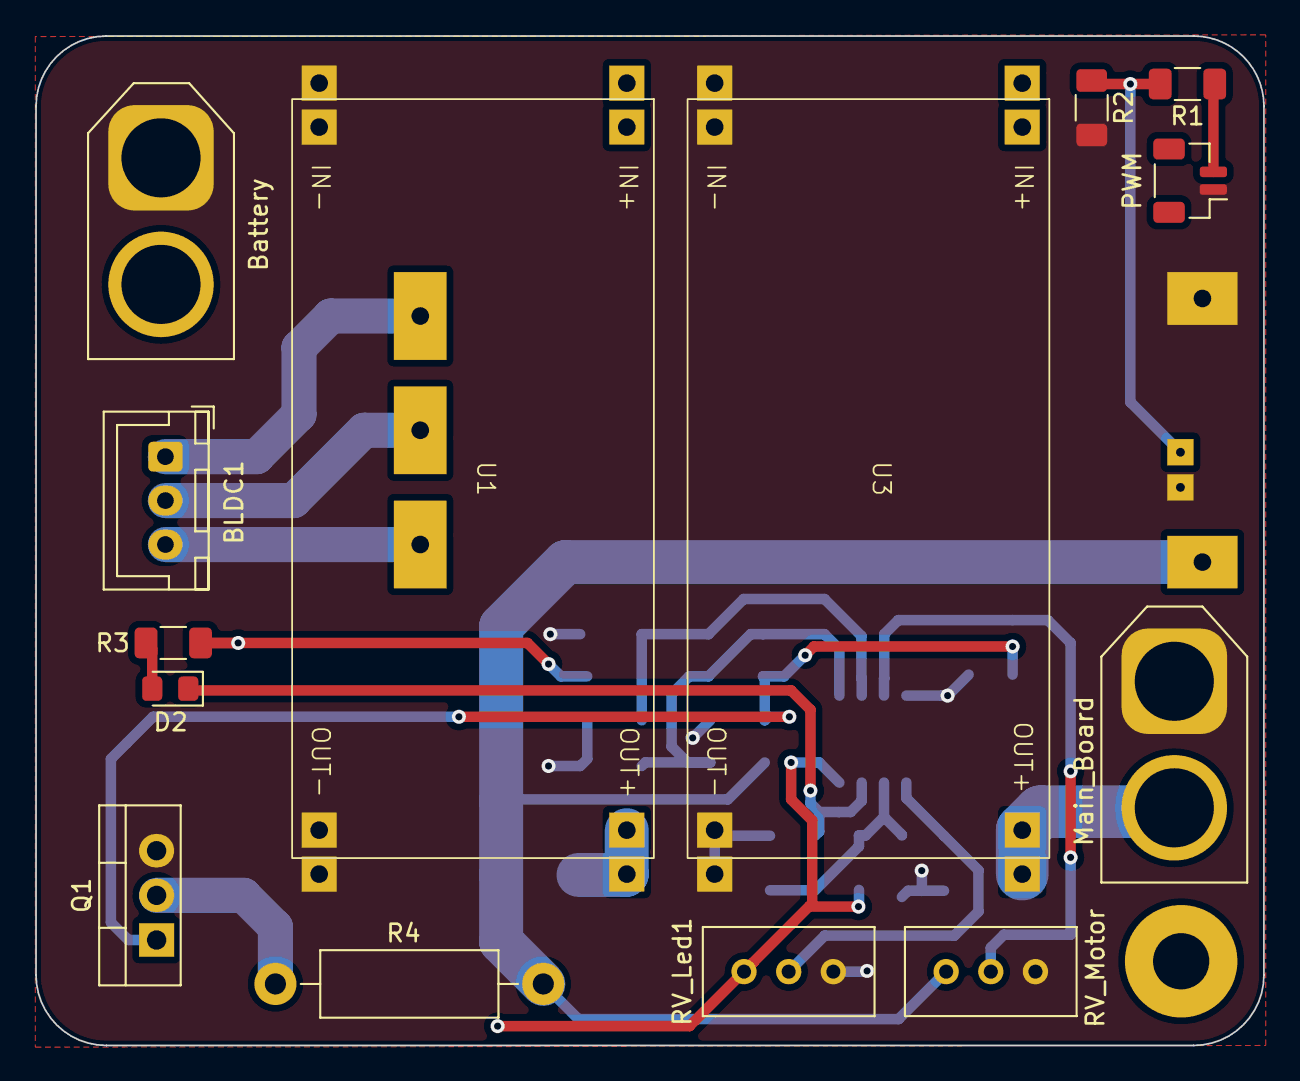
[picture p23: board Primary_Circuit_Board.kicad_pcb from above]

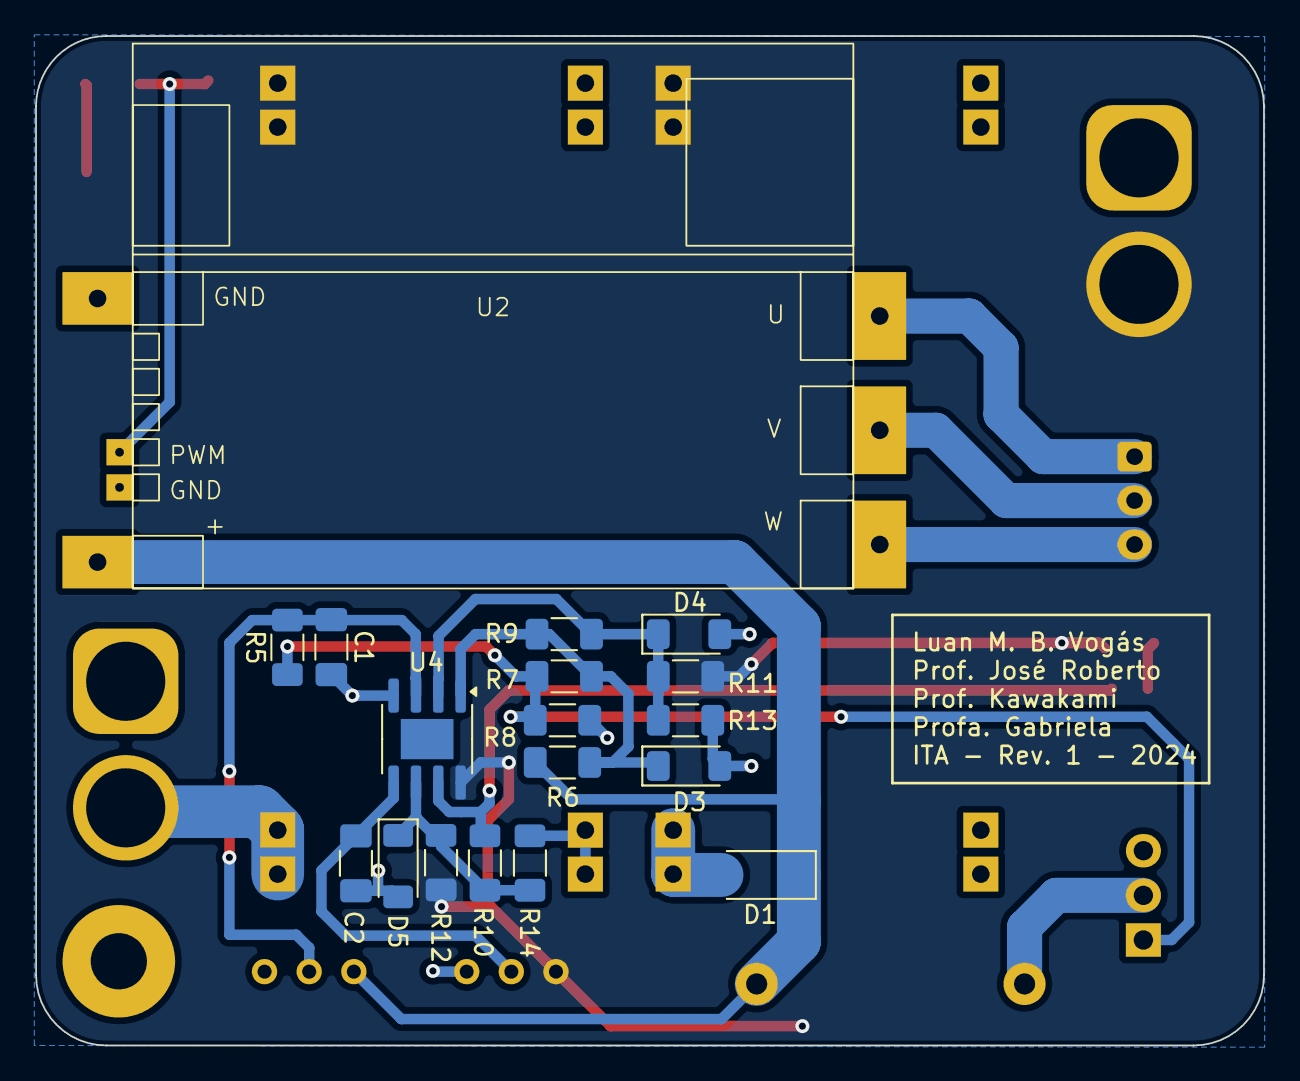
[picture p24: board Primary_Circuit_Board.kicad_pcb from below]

Board: 2 copper layers, 69.9 x 57.4 mm, 32 parts (18 on the bottom side), 19 nets.

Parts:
BLDC1: JST_XH_B3B-XH-A_1x03_P2.50mm_Vertical
Battery: Battery; AMASS_XT60-M_1x02_P7.20mm_Vertical
C1, C2: 100n; C_1206_3216Metric_Pad1.33x1.80mm_HandSolder
D1: STPS5H100AF; D_SOD-128
D2: LED; LED_0805_2012Metric_Pad1.15x1.40mm_HandSolder
D3: ZMM12; D_MiniMELF
D4, D5: ZMM3V3; D_MiniMELF
Main_Board: AMASS_XT60-F_1x02_P7.20mm_Vertical
PWM: JST_SH_BM02B-SRSS-TB_1x02-1MP_P1.00mm_Vertical
Q1: IRFZ44N; TO-220-3_Vertical
R1: 18k; R_1206_3216Metric_Pad1.30x1.75mm_HandSolder
R2, R8: 10k; R_1206_3216Metric_Pad1.30x1.75mm_HandSolder
R3: 470r; R_1206_3216Metric_Pad1.30x1.75mm_HandSolder
R4: 1r 1W; R_Axial_DIN0411_L9.9mm_D3.6mm_P15.24mm_Horizontal
R5, R9, R10, R13, R14: Reserved; R_1206_3216Metric_Pad1.30x1.75mm_HandSolder
R6: 1k; R_1206_3216Metric_Pad1.30x1.75mm_HandSolder
R7: 10r; R_1206_3216Metric_Pad1.30x1.75mm_HandSolder
R11, R12: 270r; R_1206_3216Metric_Pad1.30x1.75mm_HandSolder
RV_Led1: 10k; Potentiometer_Bourns_3296W_Vertical
RV_Motor: 10k; Potentiometer_Bourns_3296W_Vertical
U1, U3: XL6009_2A_Module
U2: B-G431B-ESC1
U4: LM393; SOIC-8-1EP_3.9x4.9mm_P1.27mm_EP2.29x3mm

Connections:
+12V: D1.1 (K), R4.1, R6.1, RV_Motor.1, U2.4 (+)
/Jumper: Q1.1 (G), R5.1, R7.1, R8.1
/Vbat: Battery.2, R3.1, R11.1, R12.1, RV_Led1.1, U1.1 (IN+), U3.1 (IN+), U4.8 (V+)
GND: Battery.1, C1.2, C2.2, D3.2 (A), D4.2 (A), D5.2 (A), Main_Board.1, PWM.1, Q1.3 (S), R2.2, R8.2, R13.2, R14.2, RV_Led1.3, RV_Motor.3, U1.2 (IN-), U1.3 (OUT-), U2.1 (GND), U2.3 (GND), U3.2 (IN-), U3.3 (OUT-), U4.4 (V-)
unnamed: BLDC1.1, U2.7 (U)
unnamed: BLDC1.2, U2.6 (V)
unnamed: BLDC1.3, U2.5 (W)
unnamed: D1.2 (A), U1.4 (OUT+)
unnamed: D2.2 (A), R3.2
unnamed: D2.1 (K), R10.2, U4.7
unnamed: D3.1 (K), R6.2, R7.2, R9.2, U4.1
unnamed: D4.1 (K), R9.1, R11.2, R13.1, U4.2 (-)
unnamed: D5.1 (K), R10.1, R12.2, R14.1, U4.6 (-)
unnamed: Main_Board.2, U3.4 (OUT+)
unnamed: PWM.2, R1.1
unnamed: Q1.2 (D), R4.2
unnamed: R1.2, R2.1, U2.2 (PWM)
unnamed: C1.1, R5.2, RV_Motor.2, U4.3 (+)
unnamed: C2.1, RV_Led1.2, U4.5 (+)

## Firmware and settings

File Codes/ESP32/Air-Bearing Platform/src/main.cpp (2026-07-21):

/******************************************************************************
 * Design, modeling, and control of a low-cost air-bearing platform
 *
 * Software developed as part of the doctoral thesis.
 *
 * Author:      Luan Mateus Bocalan Vogás
 * Advisor:     Prof. Dr. Roberto Kawakami Harrop Galvão
 * Co-Advisor:  Profa. Dra. Gabriela Werner Gabriel
 *
 * Instituto Tecnológico de Aeronáutica (ITA)
 * Electronics Engineering Division
 * São José dos Campos, SP, Brazil
 * 2026
 ******************************************************************************/

#include "hid.h"
#include "tasks.h"
#include "radio.h"
#include "motors.h"
#include "i2c.h"
#include "interrupts.h"

void setup() 
{  
  pwmInit();
  initInterruptService();
  powerInit();
  escInit();
  ledBuiltInInit();      
  serialInit();  
  gyroscopeInit();
  radioInit();
  xTaskCreate(taskPowerButton, "Power_Off_Task", 4096, NULL, 10, &handleTaskPowerButton);
  xTaskCreate(taskRadio, "Radio_Task", 4096, NULL, 9, &handleTaskRadio);
}

void loop() 
{
}

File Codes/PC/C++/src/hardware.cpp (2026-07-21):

#include "hardware.h"

void updateGyroData(gyroscopeData_t& gyroData)
{
	double sensitivity = 14.375; // Sensitivity ITG-3205	

	gyroData.x = (gyroData.xRaw - gyroData.xOffset) / sensitivity;
	gyroData.y = (gyroData.yRaw - gyroData.yOffset) / sensitivity;
	gyroData.z = (gyroData.zRaw - gyroData.zOffset) / sensitivity;
}

void getAngularVelocity(motorData_t motors, gyroscopeData_t& gyroData)
{
	bool validReading = false;
	while (validReading == false)
	{
		radioCommunicate(motors,
			             gyroData);
		updateGyroData(gyroData);

		if ((gyroData.xRaw != 0) && (gyroData.yRaw != 0) && (gyroData.zRaw != 0))
			validReading = true;
		else
			myDelayUs(500);
			
	}
}

void gyroOffsetDetermination(gyroscopeData_t &gyroData)
{
	startTimerGyro();

	// Variables
	motorData_t motor;
	double time = getTimeTimerGyro();
	double aquitisionTime = 5; // Seconds
	double sumX, sumY, sumZ;
	int sampleCounter = 0;

	sumX = 0;
	sumY = 0;
	sumZ = 0;

	cout << "Determining gyro offset... ";

	while (getTimeTimerGyro() < (time + aquitisionTime))
	{
		double startTime = getTimeTimerGyro();
		sampleCounter += 1;
		getAngularVelocity(motor, gyroData);

		sumX += gyroData.xRaw;
		sumY += gyroData.yRaw;
		sumZ += gyroData.zRaw;

		myDelayUs((0.01 - (getTimeTimerGyro() - startTime)) * 1e6);
	}

	cout << endl;
	cout << endl;

	gyroData.xOffset = sumX / sampleCounter;
	gyroData.yOffset = sumY / sampleCounter;
	gyroData.zOffset = sumZ / sampleCounter;
	
	cout << "Offset determined!" << endl;
	cout << endl;
}

void hardwareInit(gyroscopeData_t& gyroData)
{
	visionInit();
	radioInit();
	gyroOffsetDetermination(gyroData);
}

void forceDecomposition(motorData_t &motor, platformControl_t control, double rotation)
{
	double Fx = control.xAxisForce;
	double Fy = control.yAxisForce;
	double theta = rotation;
	double delta;

	double F = sqrt(pow(Fx, 2) + pow(Fy, 2));
	double gamma = atan2(Fy, Fx) * 180 / M_PI;
	if (gamma < 0) gamma += 360;	

	if (gamma-theta >= 0 && gamma - theta < 120)
	{
		delta = gamma - theta;
		motor.M3.force = (2 / sqrt(3)) * F * sin((120 - delta) * M_PI / 180);
		motor.M4.force = (2 / sqrt(3)) * F * sin(delta * M_PI / 180);
		motor.M5.force = 0;
	}
	if (gamma - theta >= 120 && gamma - theta < 240)
	{
		delta = gamma - 120 - theta;
		motor.M3.force = 0;
		motor.M4.force = (2 / sqrt(3)) * F * sin((120 - delta) * M_PI / 180);
		motor.M5.force = (2 / sqrt(3)) * F * sin(delta * M_PI / 180);		
	}
	if (gamma - theta >= 240 && gamma - theta < 360)
	{
		delta = gamma - 240 - theta;
		motor.M3.force = (2 / sqrt(3)) * F * sin(delta * M_PI / 180);
		motor.M4.force = 0;
		motor.M5.force = (2 / sqrt(3)) * F * sin((120 - delta) * M_PI / 180);
	}
	if (gamma - theta < 0 && gamma - theta >= -120)
	{
		delta = gamma - (theta - 120);
		motor.M3.force = (2 / sqrt(3)) * F * sin(delta * M_PI / 180);
		motor.M4.force = 0;
		motor.M5.force = (2 / sqrt(3)) * F * sin((120 - delta) * M_PI / 180);
	}
	if (gamma - theta < -120 && gamma - theta >= -240)
	{
		delta = gamma - (theta - 240);
		motor.M3.force = 0;
		motor.M4.force = (2 / sqrt(3)) * F * sin((120 - delta) * M_PI / 180);
		motor.M5.force = (2 / sqrt(3)) * F * sin(delta * M_PI / 180);
	}
	if (gamma - theta < -120 && gamma - theta >= -240)
	{
		delta = gamma - (theta - 240);
		motor.M3.force = 0;
		motor.M4.force = (2 / sqrt(3)) * F * sin((120 - delta) * M_PI / 180);
		motor.M5.force = (2 / sqrt(3)) * F * sin(delta * M_PI / 180);
	}
	if (gamma - theta < -240 && gamma - theta >= -360)
	{
		delta = gamma - (theta - 360);
		motor.M3.force = (2 / sqrt(3)) * F * sin((120 - delta) * M_PI / 180);
		motor.M4.force = (2 / sqrt(3)) * F * sin(delta * M_PI / 180);
		motor.M5.force = 0;
	}
}

double force2DutyCycle(double a, double b, double c, double d, double transition, double force)
{
	double dutyCycle;

	// Force to duty cycle conversion
	if (force < transition)		
		dutyCycle = (-b + sqrt(pow(b,2) + 4 * a * force)) / (2 * a);
	else
		dutyCycle = (force - d)/c;

	return dutyCycle;
}

uint8_t force2DutyCycleM1(motorDefinitions_t &motor)
{
	double dutyCycle;

	if (motor.force >= 0.0)
	{
		// Pusher operation mode
		motor.directionRotation = 1;
		dutyCycle = force2DutyCycle(4.9125e-05, 4.5293e-04, 3.3729e-03, -4.3385e-02, 5.7801e-02, motor.force);
	}
	else
	{
		// Tractor operation mode
		motor.directionRotation = 0;
		dutyCycle = force2DutyCycle(9.2423e-05, 8.4151e-04, 6.1821e-03, -7.7036e-02, 1.0843e-01, -motor.force);
	}

	return static_cast<uint8_t>(round(dutyCycle));
}

uint8_t force2DutyCycleM2(motorDefinitions_t &motor)
{
	double dutyCycle;

	if (motor.force >= 0.0)
	{
		// Tractor operation mode
		motor.directionRotation = 0;	
		dutyCycle = force2DutyCycle(9.2112e-05, 7.8728e-04, 6.1999e-03, -7.9478e-02, 1.0652e-01, motor.force);
		
	}
	else
	{
		// Pusher operation mode
		motor.directionRotation = 1;
		dutyCycle = force2DutyCycle(5.3569e-05, 2.6940e-04, 3.4049e-03, -4.5852e-02, 5.6294e-02, -motor.force);
	}

	return static_cast<uint8_t>(round(dutyCycle));
}
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

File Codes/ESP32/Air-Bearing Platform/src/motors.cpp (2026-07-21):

#include "motors.h"
#include "message.h"
#include "driver/mcpwm.h"
#include "soc/mcpwm_periph.h"
#include "hid.h"

// Based on
// https://www.arduinoecia.com.br/como-usar-pcf8574-expansor-de-portas-i2c/
// https://lastminuteengineers.com/esp32-pwm-tutorial/#:~:text=The%20ESP32's%20PWM%20resolution%20can,(216)%20different%20levels.


uint32_t pwmFrequencyAllMotors = 1e5; // 100 kHz
unsigned long int resolution = 1e7; // 10 MHz -> (10M / 100k = 100 divisions)

void pwmMotor1Init()
{
    mcpwm_timer_set_resolution(MCPWM_UNIT_0, MCPWM_TIMER_0, resolution);

    mcpwm_gpio_init(MCPWM_UNIT_0, MCPWM0A, pinPwmMotor1);
    mcpwm_config_t pwmConfigMotor1;
    pwmConfigMotor1.frequency = pwmFrequencyAllMotors;  
    pwmConfigMotor1.cmpr_a = 0;                           
    pwmConfigMotor1.cmpr_b = 0;                          
    pwmConfigMotor1.counter_mode = MCPWM_UP_COUNTER;
    pwmConfigMotor1.duty_mode = MCPWM_DUTY_MODE_0;
    mcpwm_init(MCPWM_UNIT_0, MCPWM_TIMER_0, &pwmConfigMotor1);
}

void pwmMotor2Init()
{
    
    mcpwm_timer_set_resolution(MCPWM_UNIT_0, MCPWM_TIMER_1, resolution);

    mcpwm_gpio_init(MCPWM_UNIT_0, MCPWM1A, pinPwmMotor2);
    mcpwm_config_t pwmConfigMotor2;
    pwmConfigMotor2.frequency = pwmFrequencyAllMotors;    
    pwmConfigMotor2.cmpr_a = 0;                           
    pwmConfigMotor2.cmpr_b = 0;                           
    pwmConfigMotor2.counter_mode = MCPWM_UP_COUNTER;
    pwmConfigMotor2.duty_mode = MCPWM_DUTY_MODE_0;
    mcpwm_init(MCPWM_UNIT_0, MCPWM_TIMER_1, &pwmConfigMotor2);
}

void pwmMotor3Init()
{
    mcpwm_timer_set_resolution(MCPWM_UNIT_0, MCPWM_TIMER_2, resolution);

    mcpwm_gpio_init(MCPWM_UNIT_0, MCPWM2A, pinPwmMotor3);
    mcpwm_config_t pwmConfigMotor3;
    pwmConfigMotor3.frequency = pwmFrequencyAllMotors;   
    pwmConfigMotor3.cmpr_a = 0;                           
    pwmConfigMotor3.cmpr_b = 0;                           
    pwmConfigMotor3.counter_mode = MCPWM_UP_COUNTER;
    pwmConfigMotor3.duty_mode = MCPWM_DUTY_MODE_0;
    mcpwm_init(MCPWM_UNIT_0, MCPWM_TIMER_2, &pwmConfigMotor3);
}

void pwmMotor4Init()
{
    mcpwm_timer_set_resolution(MCPWM_UNIT_1, MCPWM_TIMER_0, resolution);

    mcpwm_gpio_init(MCPWM_UNIT_1, MCPWM0A, pinPwmMotor4);
    mcpwm_config_t pwmConfigMotor4;
    pwmConfigMotor4.frequency = pwmFrequencyAllMotors;   
    pwmConfigMotor4.cmpr_a = 0;                           
    pwmConfigMotor4.cmpr_b = 0;                           
    pwmConfigMotor4.counter_mode = MCPWM_UP_COUNTER;
    pwmConfigMotor4.duty_mode = MCPWM_DUTY_MODE_0;
    mcpwm_init(MCPWM_UNIT_1, MCPWM_TIMER_0, &pwmConfigMotor4);
}

void pwmMotor5Init()
{
    mcpwm_timer_set_resolution(MCPWM_UNIT_1, MCPWM_TIMER_1, resolution);

    mcpwm_gpio_init(MCPWM_UNIT_1, MCPWM1A, pinPwmMotor5);
    mcpwm_config_t pwmConfigMotor5;
    pwmConfigMotor5.frequency = pwmFrequencyAllMotors;   
    pwmConfigMotor5.cmpr_a = 0;                           
    pwmConfigMotor5.cmpr_b = 0;                           
    pwmConfigMotor5.counter_mode = MCPWM_UP_COUNTER;
    pwmConfigMotor5.duty_mode = MCPWM_DUTY_MODE_0;
    mcpwm_init(MCPWM_UNIT_1, MCPWM_TIMER_1, &pwmConfigMotor5);
}

void pwmMotor6Init()
{
    mcpwm_timer_set_resolution(MCPWM_UNIT_1, MCPWM_TIMER_2, resolution);

    mcpwm_gpio_init(MCPWM_UNIT_1, MCPWM2A, pinPwmMotor6);
    mcpwm_config_t pwmConfigMotor6;
    pwmConfigMotor6.frequency = 490;   
    pwmConfigMotor6.cmpr_a = 0;                           
    pwmConfigMotor6.cmpr_b = 0;                           
    pwmConfigMotor6.counter_mode = MCPWM_UP_COUNTER;
    pwmConfigMotor6.duty_mode = MCPWM_DUTY_MODE_0;
    mcpwm_init(MCPWM_UNIT_1, MCPWM_TIMER_2, &pwmConfigMotor6);    
}

void disableHBridges()
{     
    Wire.beginTransmission(32);
    Wire.write(0b00000000);
    Wire.endTransmission();
}

void pwmInit()
{   
    Wire.begin();  

    disableHBridges();

    pwmMotor1Init();  
    pwmMotor2Init();
    pwmMotor3Init();
    pwmMotor4Init();
    pwmMotor5Init();
    pwmMotor6Init();

    setPwmMotor1(0);
    setPwmMotor2(0);
    setPwmMotor3(0);
    setPwmMotor4(0);
    setPwmMotor5(0);
    setPwmMotor6(0);      
}

void escInit()
{   bool bit0 = 1;
    bool bit1 = 0;
    bool bit2 = 0;
    bool bit3 = 0;
    bool bit4 = 0;
    bool bit5 = 0;
    bool bit6 = 0;
    bool bit7 = 0;

    Wire.beginTransmission(32);
    Wire.write(bit7 << 7 | bit6 << 6 | bit5 << 5 | bit4 << 4 | bit3 << 3 | bit2 << 2 | bit1 << 1 | bit0 << 0);
    Wire.endTransmission(); 
    
    setPwmMotor6(1060);
    delay(500);
    setPwmMotor6(1860);
    delay(500);
    setPwmMotor6(1460);
}

void setPwmMotor1(float dutyPwmMotor1)
{
    mcpwm_set_duty(MCPWM_UNIT_0, MCPWM_TIMER_0, MCPWM_OPR_A, dutyPwmMotor1);
}

void setPwmMotor2(float dutyPwmMotor2)
{
    mcpwm_set_duty(MCPWM_UNIT_0, MCPWM_TIMER_1, MCPWM_OPR_A, dutyPwmMotor2);
}

void setPwmMotor3(float dutyPwmMotor3)
{
    mcpwm_set_duty(MCPWM_UNIT_0, MCPWM_TIMER_2, MCPWM_OPR_A, dutyPwmMotor3);
}

void setPwmMotor4(float dutyPwmMotor4)
{
    mcpwm_set_duty(MCPWM_UNIT_1, MCPWM_TIMER_0, MCPWM_OPR_A, dutyPwmMotor4);
}

void setPwmMotor5(float dutyPwmMotor5)
{
    mcpwm_set_duty(MCPWM_UNIT_1, MCPWM_TIMER_1, MCPWM_OPR_A, dutyPwmMotor5);
}

void setPwmMotor6(float dutyPwmMotor6)
{
    mcpwm_set_duty_in_us(MCPWM_UNIT_1, MCPWM_TIMER_2, MCPWM_OPR_A, dutyPwmMotor6);
}

void setMotorDirection()
{
    bool bit0 = rxMsg.msgs[whoAmI-1].msgMotorParameters.enableHBridges;
    bool bit1 = rxMsg.msgs[whoAmI-1].msgMotorParameters.directionMotor1;
    bool bit2 = rxMsg.msgs[whoAmI-1].msgMotorParameters.directionMotor2;
    bool bit3 = rxMsg.msgs[whoAmI-1].msgMotorParameters.directionMotor3;
    bool bit4 = rxMsg.msgs[whoAmI-1].msgMotorParameters.directionMotor4;
    bool bit5 = rxMsg.msgs[whoAmI-1].msgMotorParameters.directionMotor5;
    bool bit6 = rxMsg.msgs[whoAmI-1].msgMotorParameters.directionMotor6;
    bool bit7 = rxMsg.msgs[whoAmI-1].msgMotorParameters.reserved;

    Wire.beginTransmission(32);
    Wire.write(bit7 << 7 | bit6 << 6 | bit5 << 5 | bit4 << 4 | bit3 << 3 | bit2 << 2 | bit1 << 1 | bit0 << 0);
    Wire.endTransmission(); 
}

void setPwmAllMotors()
{
    if(rxMsg.msgs[whoAmI-1].msgMotorParameters.enableHBridges)
    {
        setPwmMotor1(rxMsg.msgs[whoAmI-1].msgDutyPwmMotor1);
        setPwmMotor2(rxMsg.msgs[whoAmI-1].msgDutyPwmMotor2);
        setPwmMotor3(rxMsg.msgs[whoAmI-1].msgDutyPwmMotor3);
        setPwmMotor4(rxMsg.msgs[whoAmI-1].msgDutyPwmMotor4);
        setPwmMotor5(rxMsg.msgs[whoAmI-1].msgDutyPwmMotor5);
        setPwmMotor6(rxMsg.msgs[whoAmI-1].msgDutyPwmMotor6);
        setMotorDirection();
    }
    else 
    {
        disableHBridges();
        disableAllMotors();
    }
    
}

void disableAllMotors()
{
    setPwmMotor1(0);
    setPwmMotor2(0);
    setPwmMotor3(0);
    setPwmMotor4(0);
    setPwmMotor5(0);
    setPwmMotor6(0);
}

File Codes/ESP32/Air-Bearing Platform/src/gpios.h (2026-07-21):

#ifndef _FIRMWARE_GPIOS
#define _FIRMWARE_GPIOS

#include <Arduino.h>
#include "driver/gpio.h"

#define pinLedBuiltIn     GPIO_NUM_2
#define pinPowerButton    GPIO_NUM_13
#define pinEnable3V3      GPIO_NUM_12
#define pinPwmMotor1      GPIO_NUM_14
#define pinPwmMotor2      GPIO_NUM_27
#define pinPwmMotor3      GPIO_NUM_26
#define pinPwmMotor4      GPIO_NUM_25
#define pinPwmMotor5      GPIO_NUM_33
#define pinPwmMotor6      GPIO_NUM_32
#define pinRadioInterrupt GPIO_NUM_17
#define pinI2cSda         GPIO_NUM_21
#define pinI2cScl         GPIO_NUM_22

#endif // _FIRMWARE_GPIOS
